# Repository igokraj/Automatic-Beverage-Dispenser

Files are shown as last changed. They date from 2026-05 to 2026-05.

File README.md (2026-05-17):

# Automatic Beverage Dispenser

# 3D view of the board
```bash
Images
```
Hardware design of a control unit for an automatic beverage dispenser. The system manages liquid pump operations based on readings from a hardware flow sensor. 

## Hardware Specifications
* **Microcontroller:** 32-bit STM32G030F6P6 in a TSSOP20 package.
* **Power Supply:** 12V DC via a barrel jack connector. The power path is protected by a 1812L150/24 resettable fuse against short circuits, an SMBJ15A TVS diode against overvoltage spikes, and a B340 Schottky diode against reverse polarity. The digital logic is powered by an AMS1117-3.3 LDO regulator.
* **Power Stage:** An AO3400 N-Channel MOSFET operating as a low-side switch to control the liquid pump. The inductive load is protected by an SS14 flyback diode.
* **Input Interfaces:** Three user buttons (UP, DOWN, START) equipped with hardware RC debouncing circuits. The flow sensor input utilizes a resistor voltage divider (27k/10k) to safely step down the 12V signal to a 3.3V logic level.
* **External Communication:** An I2C bus with hardware 4.7k pull-up resistors to 3.3V, alongside a standard SWD header for microcontroller programming and debugging.
* **PCB:** Two-layer FR-4 board utilizing copper pours to minimize electromagnetic interference (EMI).

## Repository Structure
* `/Production` - A complete set of manufacturing files optimized for PCBA assembly (Gerber files, Excellon drill files, CSV BOM, and Pick & Place CPL file).
* Files in the root directory represent the printed circuit board project sources, designed in KiCad.

## Installation
Clone this repository to your local machine:
```bash
git clone https://github.com/igokraj/Automatic-Beverage-Dispenser.git
cd Automatic-Beverage-Dispenser

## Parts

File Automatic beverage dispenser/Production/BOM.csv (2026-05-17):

Reference | Qty | Value | DNP | Exclude from BOM | Exclude from Board | Footprint | Datasheet | LCSC Part #
C1 | 1 | 10uF/25V/Tantalum |  |  |  | Capacitor_Tantalum_SMD:CP_EIA-3216-18_Kemet-A |  | C13585
C2 | 1 | 10uF/10V/Tantalum |  |  |  | Capacitor_Tantalum_SMD:CP_EIA-3216-18_Kemet-A |  | C7177
C3,C4,C5,C6,C7,C8 | 6 | 100nF/16V/X7R |  |  |  | Capacitor_SMD:C_0805_2012Metric |  | C49678
D1 | 1 | SMBJ15A |  |  |  | Diode_SMD:D_SMB |  | C10210
D2,D4,D5,D6,D7,D8,D9 | 7 | SS14 |  |  |  | Diode_SMD:D_SMA |  | C2168
D3 | 1 | B340_SMA |  |  |  | Diode_SMD:D_SMA |  | C64982
F1 | 1 | 1812L150/24 |  |  |  | Fuse:Fuse_1812_4532Metric |  | C9308
J1 | 1 | DC_Barrel_5.5x2.1 |  |  |  | Connector_BarrelJack:BarrelJack_Horizontal
J2 | 1 | Goldpin_1x4_2.54 |  |  |  | Connector_PinHeader_2.54mm:PinHeader_1x04_P2.54mm_Vertical
J3 | 1 | JST_XH_1x4_2.54 |  |  |  | Connector_JST:JST_XH_B4B-XH-A_1x04_P2.50mm_Vertical
J4 | 1 | ST_XH_1x2_2.54 |  |  |  | Connector_JST:JST_XH_B2B-XH-A_1x02_P2.50mm_Vertical
J5 | 1 | JST_XH_1x3_2.54 |  |  |  | Connector_JST:JST_XH_B3B-XH-A_1x03_P2.50mm_Vertical
Q1 | 1 | AO3400_SOT23 |  |  |  | Package_TO_SOT_SMD:SOT-23 |  | C20917
R1,R2 | 2 | 4.7k/1%/0.1W |  |  |  | Resistor_SMD:R_0805_2012Metric |  | C17673
R3 | 1 | 100R/1%/0.1W |  |  |  | Resistor_SMD:R_0805_2012Metric |  | C17408
R4,R6,R8,R10,R12,R14 | 6 | 10k/1%/0.1W |  |  |  | Resistor_SMD:R_0805_2012Metric |  | C17414
R5 | 1 | 27k/1%/0.1W |  |  |  | Resistor_SMD:R_0805_2012Metric |  | C2904543
R11,R13,R15 | 3 | 1k/1%/0.1W |  |  |  | Resistor_SMD:R_0805_2012Metric |  | C17513
SW1,SW2,SW3 | 3 | SW_Push |  |  |  | Button_Switch_THT:SW_PUSH_6mm_H5mm
U1 | 1 | AMS1117-3.3_SOT223 |  |  |  | Package_TO_SOT_SMD:SOT-223-3_TabPin2 | http://www.advanced-monolithic.com/pdf/ds1117.pdf | C6186
U2 | 1 | STM32G030F6P6_TSSOP20 |  |  |  | Package_SO:TSSOP-20_4.4x6.5mm_P0.65mm | https://www.st.com/resource/en/datasheet/stm32g030f6.pdf | C529330

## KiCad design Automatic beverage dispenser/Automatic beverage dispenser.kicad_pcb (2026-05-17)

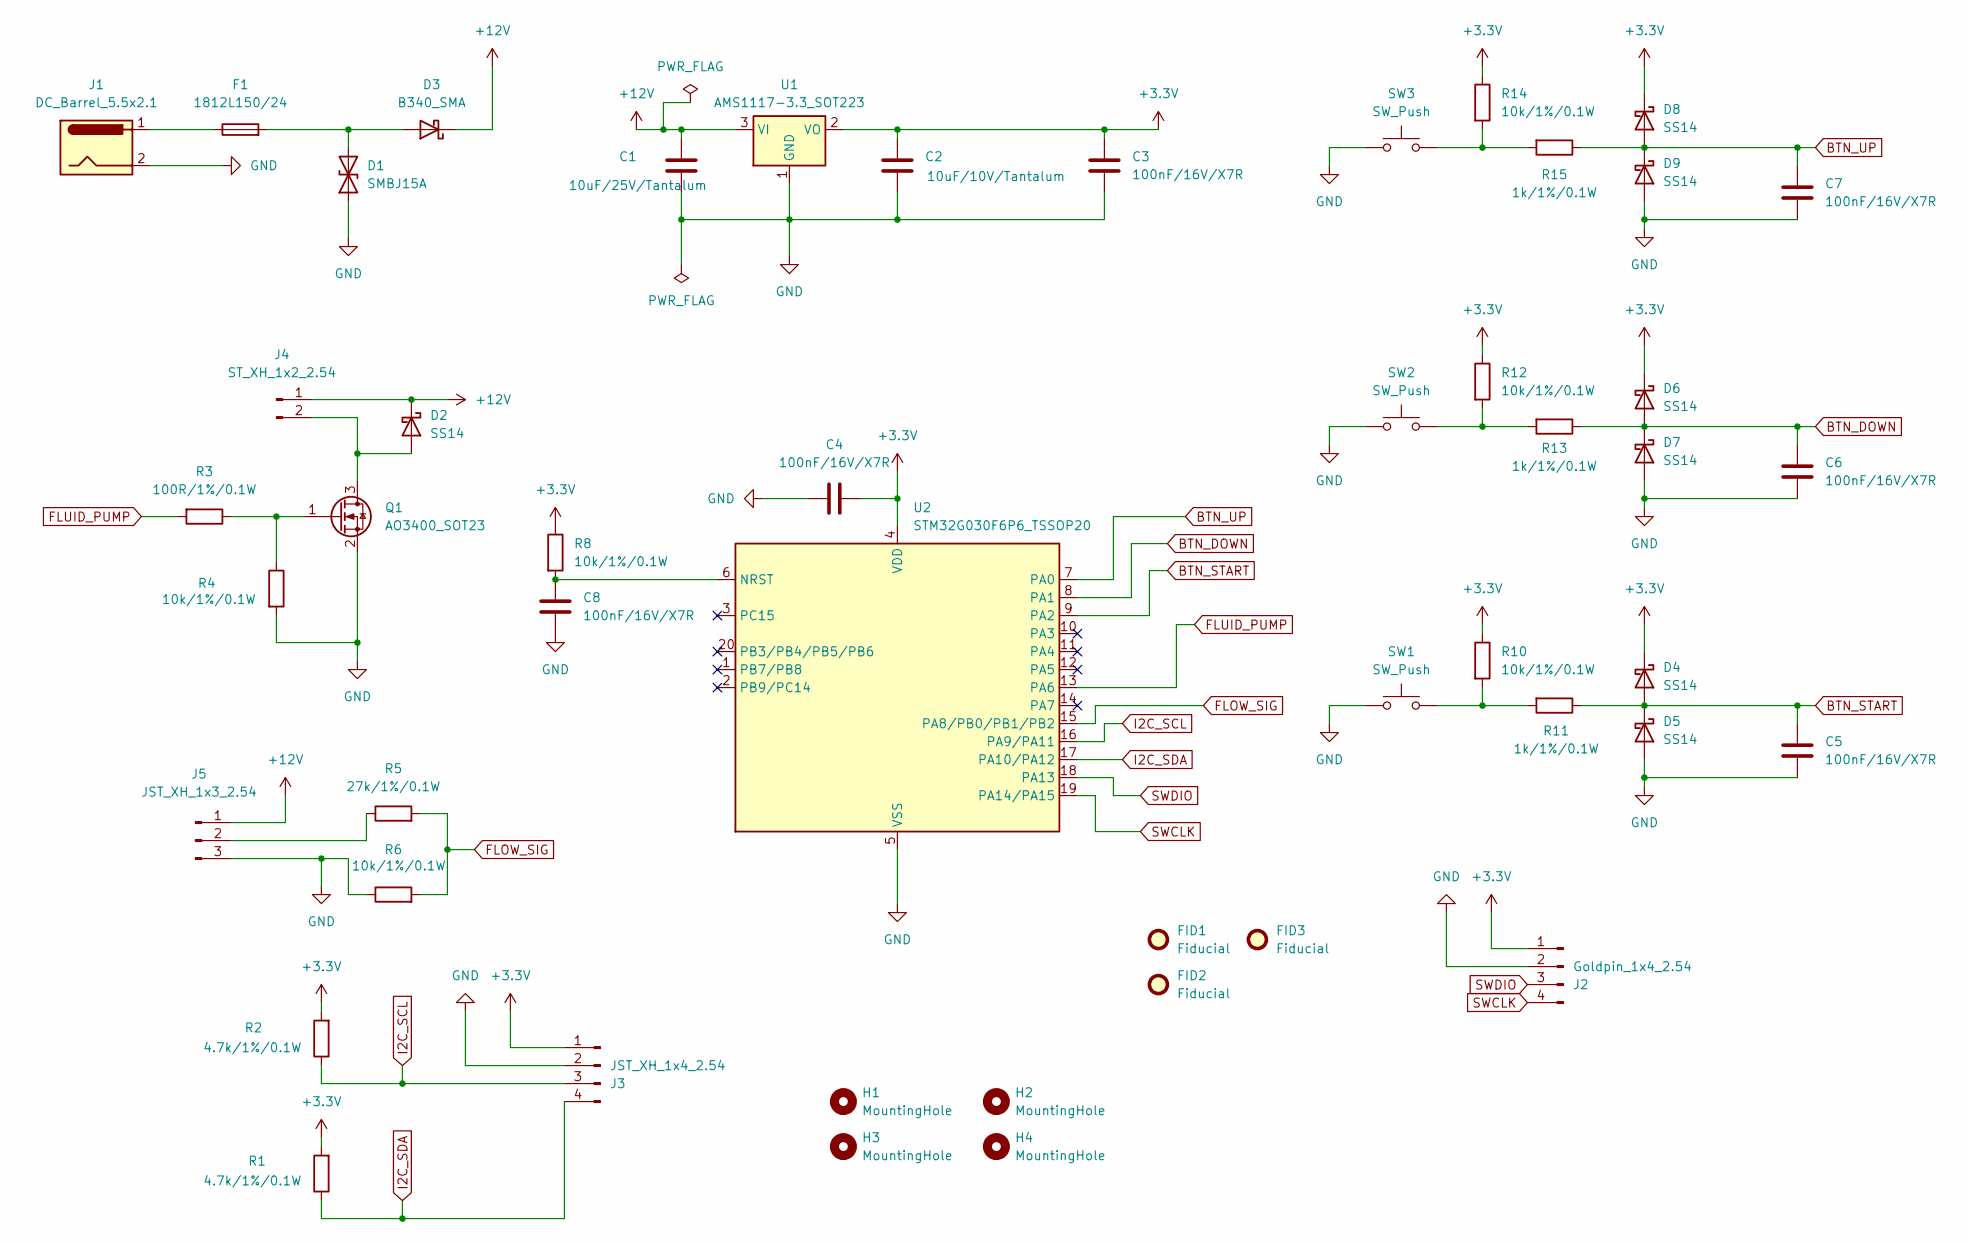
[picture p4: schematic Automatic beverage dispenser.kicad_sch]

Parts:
C1: 10uF/25V/Tantalum; CP_EIA-3216-18_Kemet-A; LCSC Part # C13585
C2: 10uF/10V/Tantalum; CP_EIA-3216-18_Kemet-A; LCSC Part # C7177
C3, C4, C5, C6, C7, C8: 100nF/16V/X7R; C_0805_2012Metric; LCSC Part # C49678
D1: SMBJ15A; D_SMB; LCSC Part # C10210
D2, D4, D5, D6, D7, D8, D9: SS14; D_SMA; LCSC Part # C2168
D3: B340_SMA; D_SMA; LCSC Part # C64982
F1: 1812L150/24; Fuse_1812_4532Metric; LCSC Part # C9308
FID1, FID2, FID3: Fiducial; Fiducial_1mm_Mask2mm
H1, H2, H3, H4: MountingHole; MountingHole_2.2mm_M2
J1: DC_Barrel_5.5x2.1; BarrelJack_Horizontal
J2: Goldpin_1x4_2.54; PinHeader_1x04_P2.54mm_Vertical
J3: JST_XH_1x4_2.54; JST_XH_B4B-XH-A_1x04_P2.50mm_Vertical
J4: ST_XH_1x2_2.54; JST_XH_B2B-XH-A_1x02_P2.50mm_Vertical
J5: JST_XH_1x3_2.54; JST_XH_B3B-XH-A_1x03_P2.50mm_Vertical
Q1: AO3400_SOT23; SOT-23; LCSC Part # C20917
R1, R2: 4.7k/1%/0.1W; R_0805_2012Metric; LCSC Part # C17673
R3: 100R/1%/0.1W; R_0805_2012Metric; LCSC Part # C17408
R4, R6, R8, R10, R12, R14: 10k/1%/0.1W; R_0805_2012Metric; LCSC Part # C17414
R5: 27k/1%/0.1W; R_0805_2012Metric; LCSC Part # C2904543
R11, R13, R15: 1k/1%/0.1W; R_0805_2012Metric; LCSC Part # C17513
SW1, SW2, SW3: SW_Push; SW_PUSH_6mm_H5mm
U1: AMS1117-3.3_SOT223; SOT-223-3_TabPin2; LCSC Part # C6186
U2: STM32G030F6P6_TSSOP20; TSSOP-20_4.4x6.5mm_P0.65mm; LCSC Part # C529330

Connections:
+3.3V: C2.1, C3.1, C4.2, D4.1 (K), D6.1 (K), D8.1 (K), J2.1, J3.1, R1.2, R2.2, R8.1, R10.1, R12.1, R14.1, U1.2 (VO), U2.4 (VDD)
+12V: C1.1, D2.1 (K), D3.1 (K), J4.1, J5.1, U1.3 (VI)
BTN_DOWN: C6.2, D6.2 (A), D7.1 (K), R13.1, U2.8 (PA1)
BTN_START: C5.2, D4.2 (A), D5.1 (K), R11.1, U2.9 (PA2)
BTN_UP: C7.2, D8.2 (A), D9.1 (K), R15.1, U2.7 (PA0)
FLOW_SIG: R5.2, R6.2, U2.15 (PA8/PB0/PB1/PB2)
FLUID_PUMP: R3.2, U2.13 (PA6)
GND: C1.2, C2.2, C3.2, C4.1, C5.1, C6.1, C7.1, C8.1, D1.1 (A1), D5.2 (A), D7.2 (A), D9.2 (A), J1.2, J2.2, J3.2, J5.3, Q1.2 (S), R4.2, R6.1, SW1.1, SW2.1, SW3.1, U1.1 (GND), U2.5 (VSS)
I2C_SCL: J3.3, R2.1, U2.16 (PA9/PA11)
I2C_SDA: J3.4, R1.1, U2.17 (PA10/PA12)
unnamed: D1.2 (A2), D3.2 (A), F1.2
unnamed: D2.2 (A), J4.2, Q1.3 (D)
unnamed: F1.1, J1.1
unnamed: J5.2, R5.1
unnamed: Q1.1 (G), R3.1, R4.1
unnamed: R10.2, R11.2, SW1.2
unnamed: R12.2, R13.2, SW2.2
unnamed: R14.2, R15.2, SW3.2
unnamed: C8.2, R8.2, U2.6 (NRST)
SWCLK: J2.4, U2.19 (PA14/PA15)
SWDIO: J2.3, U2.18 (PA13)

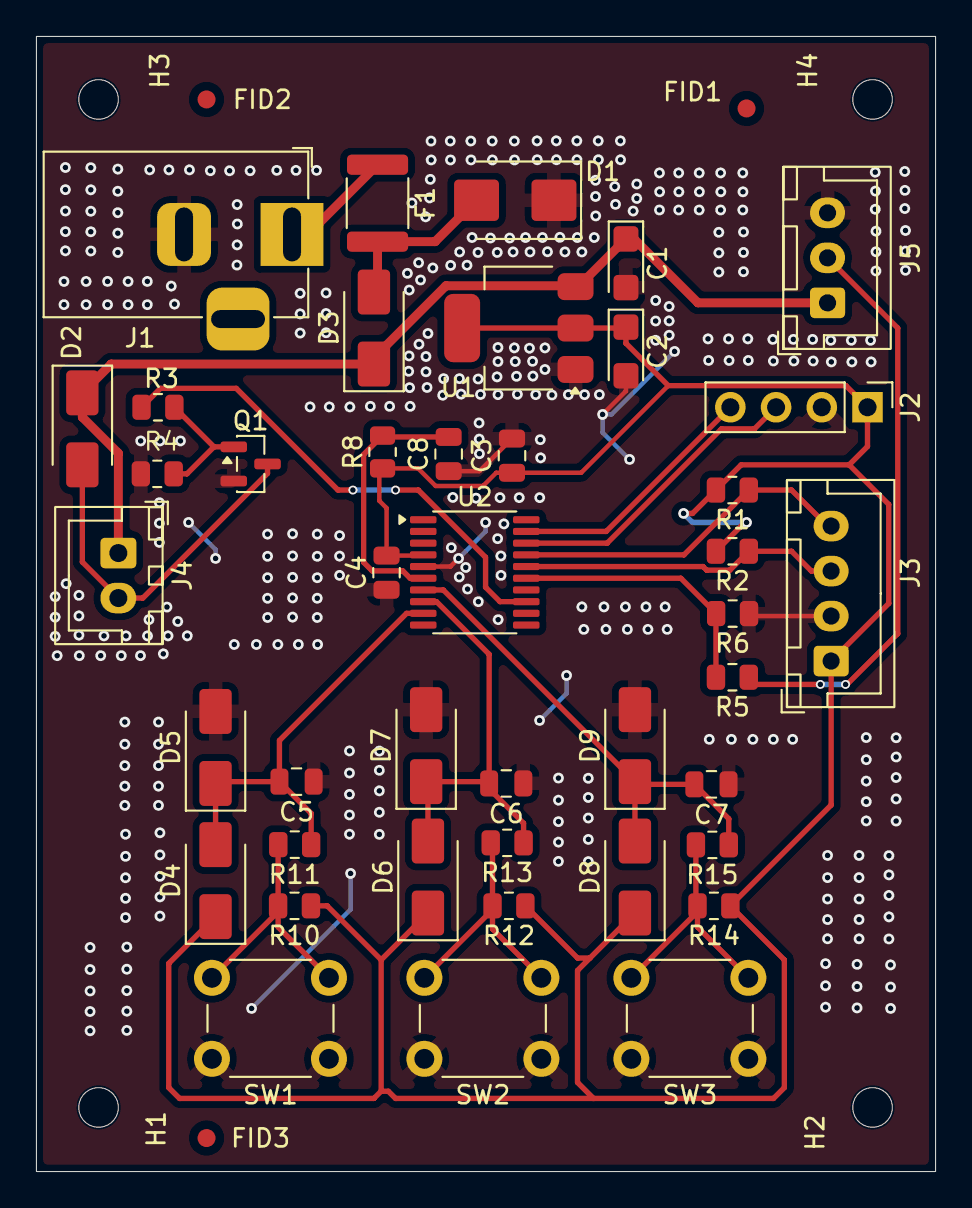
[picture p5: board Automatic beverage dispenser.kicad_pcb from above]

Board: 2 copper layers, 49.9 x 63.1 mm, 49 parts (0 on the bottom side), 21 nets.
